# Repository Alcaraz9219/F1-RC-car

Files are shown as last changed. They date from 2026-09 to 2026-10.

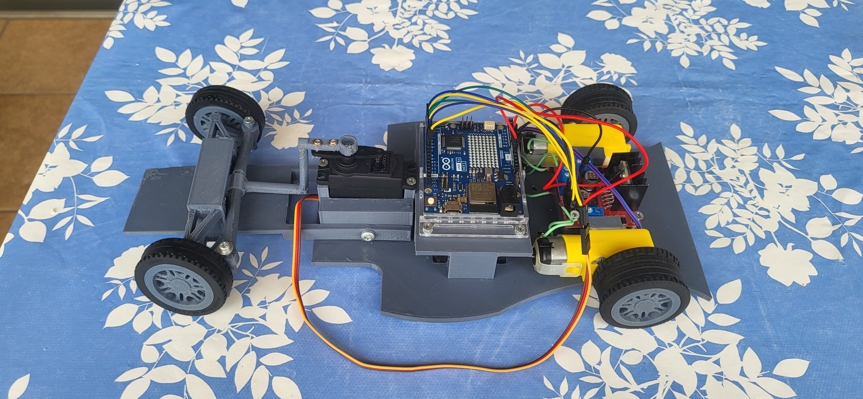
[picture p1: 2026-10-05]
Photos of the process/20260817_131121.jpg

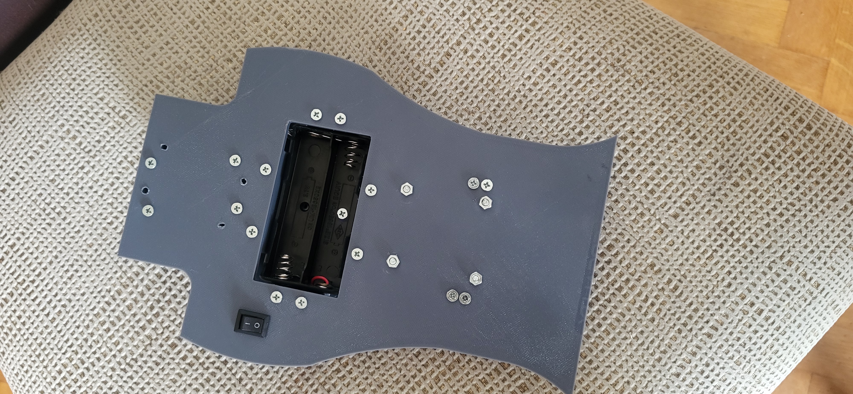
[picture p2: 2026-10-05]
Photos of the process/20260703_114534 (1).jpg

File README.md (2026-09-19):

🏎️ F1 RC Car

A custom-built, 3D-printed remote-controlled racing car inspired by Formula 1.

This project was developed as a hands-on electronics, CAD, 3D printing and programming project. The goal was to design and build the car from scratch, including the chassis, wheels, steering system and aerodynamic parts, while learning how the different electronic and mechanical systems work together.

 Features:
Custom 3D-printed chassis
Formula 1-inspired body and aerodynamic design
Rear-wheel drive
Two DC geared motors
Servo-controlled front steering
Wireless remote control
Custom-designed wheels
Custom front wing and nose
Arduino-based electronics
LCD display on the controller
Accelerator and brake controls
Joystick-based steering
NRF24L01 wireless communication
Designed and modified using CAD software

 Electronics:
Car
Arduino UNO R4 WiFi
L298N motor driver
2× geared DC motors
20 kg metal gear steering servo
2× 18650 batteries
NRF24L01 PA+LNA wireless module
LM2596 buck converter
Controller
Arduino UNO R3
NRF24L01 PA+LNA wireless module
Joystick
16×2 I2C LCD
Accelerator button
Brake button

Wireless Control:

The car and controller communicate using NRF24L01 PA+LNA modules.

The controller sends the steering and driving commands wirelessly to the Arduino on the car. The NRF24L01 modules replaced the original 433 MHz RF system to provide a more reliable and capable communication system.

The communication uses the Arduino's hardware SPI interface.

 Software:

The project is programmed using Arduino/C++.

The software is divided into two main parts:

Controller:

The controller reads:

Joystick position
Accelerator button
Brake button

It then sends these values wirelessly to the car.

Car

The car receives the controller data and converts it into:

Motor direction and speed
Steering servo position

The L298N controls the two drive motors, while a servo controls the front steering.

 CAD & 3D Printing:

A large part of the project was designing the mechanical components myself.

The project includes CAD and 3D-printable files for components such as:

Chassis
Motor supports
Arduino supports
L298N support
Battery holder
Steering components
Steering linkage
Wheels
Front wing
Front nose
Other mounting components

Different versions of several parts were designed, printed and tested before reaching the final versions.

Design Process:

The car was developed iteratively rather than designing everything perfectly on the first attempt.

The general process was:

Initial F1-inspired concept
Chassis design
Design of electronic and motor mounts
3D printing and physical testing
Modification of parts that did not fit correctly
Steering mechanism development
Wheel and aerodynamic component design
Electronics assembly
Motor testing
Steering servo testing
Wireless communication development
Integration of the different systems

Testing and redesigning parts was an important part of the project.

 What I Learned

Through this project I learned about:

Arduino programming
Wireless communication
SPI communication
Motor drivers
DC motors
Servo motors
Voltage regulation
Battery-powered electronics
CAD design
3D printing
Mechanical prototyping
Iterative design
Troubleshooting electronics
Integrating hardware and software

One of the main lessons from the project was that designing a system is only part of the work. A large part of the process is testing, finding problems and redesigning the components until everything works together.

 Future Improvements

Possible future improvements include:

DRS system using an SG90 servo
Lights
Additional controller buttons
Improved bodywork
More aerodynamic components
Improved wireless communication
Additional telemetry
More advanced driving controls
 Project Status

The main car structure, steering, motors, controller and wireless communication systems have been developed and tested.

The project is currently considered a functional prototype, with additional features planned for future development.

Made as a learning project combining CAD, 3D printing, electronics and programming.

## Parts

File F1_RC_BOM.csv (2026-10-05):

Item | Quantity | Unit | Description | Estimated Price (€)
Arduino UNO R4 WiFi | 1 | unit | Main car microcontroller | 30.0
Arduino UNO R3 | 1 | unit | Remote controller microcontroller | 29.0
ESP32 Plus STEAMakers | 1 | unit | Controller prototype; ultimately not used | 30.0
20KG metal gear steering servo | 1 | unit | Front steering servo | 15.0
L298N motor driver | 1 | unit | Dual DC motor driver | 4.0
Geared DC motors | 2 | unit | Rear-wheel drive motors | 15.0
433 MHz RF transmitter/receiver set | 1 | set | Initial wireless communication system | 5.0
NRF24L01 PA+LNA modules | 2 | unit | Long-range wireless transceivers | 10.0
SG90 servo | 1 | unit | DRS actuator | 3.0
2x18650 battery holder | 1 | unit | Battery holder | 2.0
3.7 V lithium batteries | 2 | unit | 18650 cells | 10.0
LM2596 buck converter | 1 | unit | Adjustable DC-DC voltage regulator | 2.0
Terminal blocks | 6 | unit | Electrical connections | 3.0
Jumper wires | 42 | unit | Approximate quantity used | 3.0
Power switch | 1 | unit | Main power switch | 2.0
16x2 I2C LCD | 1 | unit | Remote controller display | 5.0
Joystick module | 1 | unit | Remote steering input | 2.0
Push buttons | 2 | unit | Accelerator and brake controls | 1.0
9 V battery | 1 | unit | Prototype/testing power source | 2.0
Machine screws | 56 | unit | Fasteners | 5.0
Wood screws | 4 | unit | Fasteners | 1.0
Washers | 4 | unit | Fasteners | 1.0
Nuts | 10 | unit | Fasteners | 1.0
Threaded inserts | 12 | unit | Threaded inserts for printed parts | 5.0
Tires | 4 | unit | Four wheels | 8.0
Gray PETG filament | 1 | kg roll | 3D printing material | 20.0

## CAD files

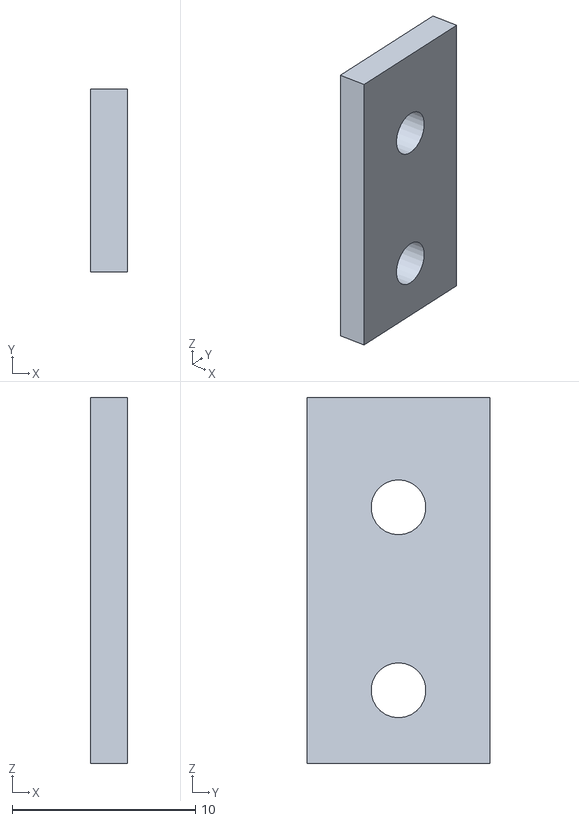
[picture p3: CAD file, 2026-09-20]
Cad/Bumper and front wing/Front bumper assembly.stl
2.00 x 10.0 x 20.0

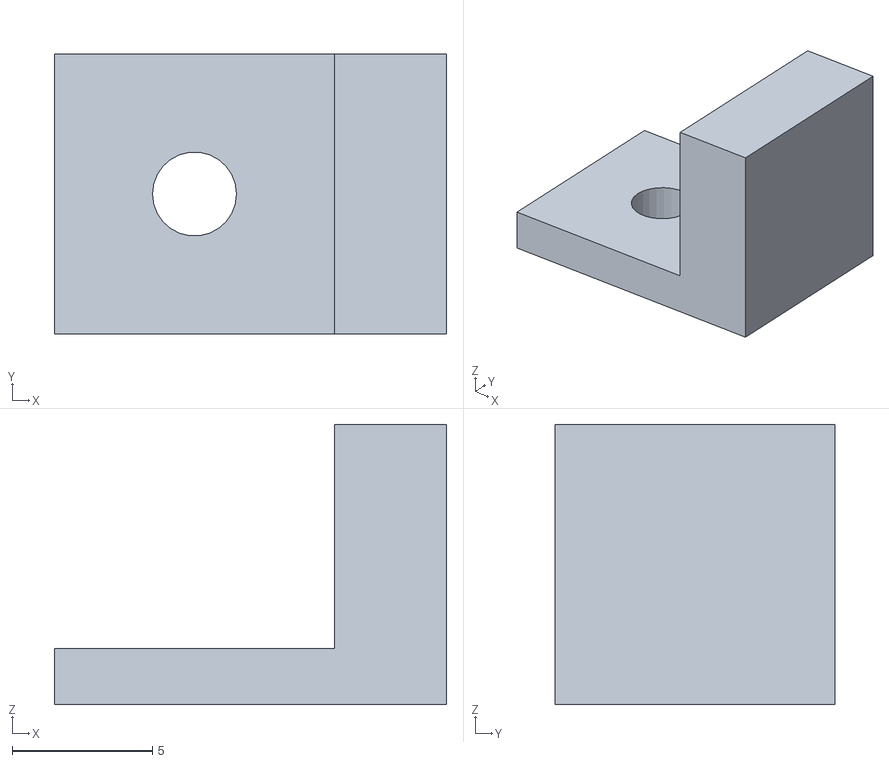
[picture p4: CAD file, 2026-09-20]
Cad/Bumper and front wing/Front bumper assembly for the above part.stl
14.0 x 10.0 x 10.0

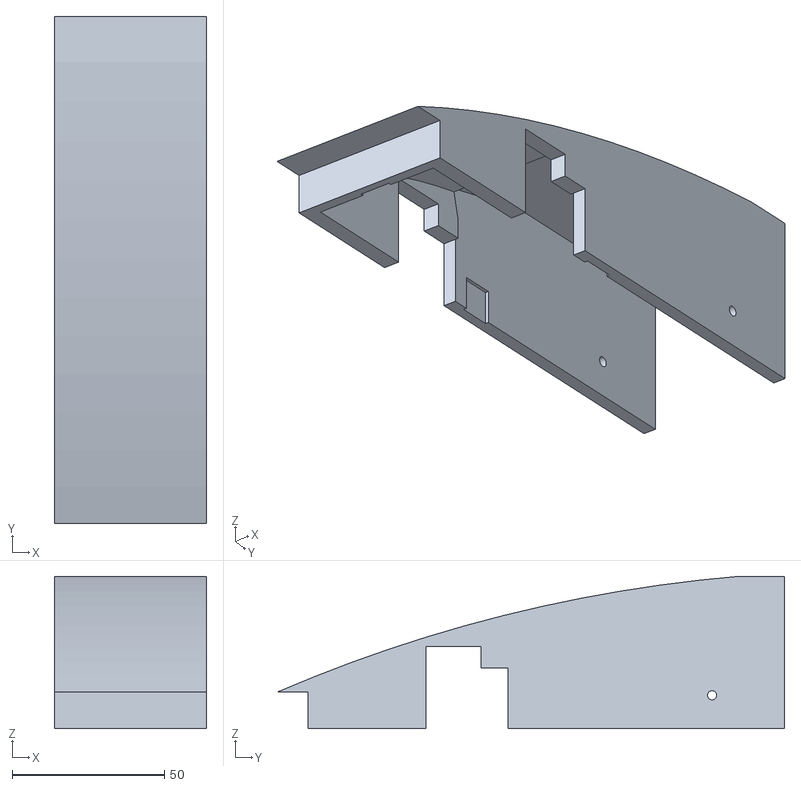
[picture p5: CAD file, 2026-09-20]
Cad/Bumper and front wing/Front bumper above part.stl
50.0 x 166.6 x 50.1

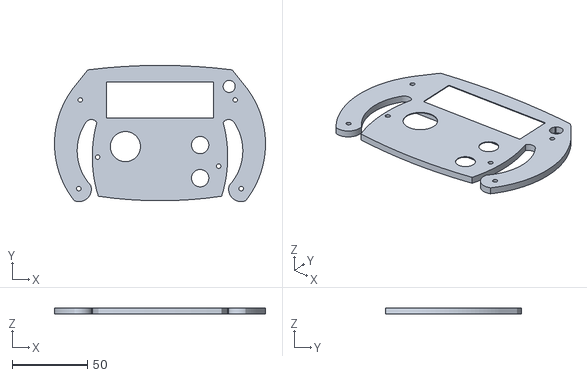
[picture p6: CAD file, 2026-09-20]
Cad/Remote control/Remote control above part.stl
140.3 x 90.6 x 4.00

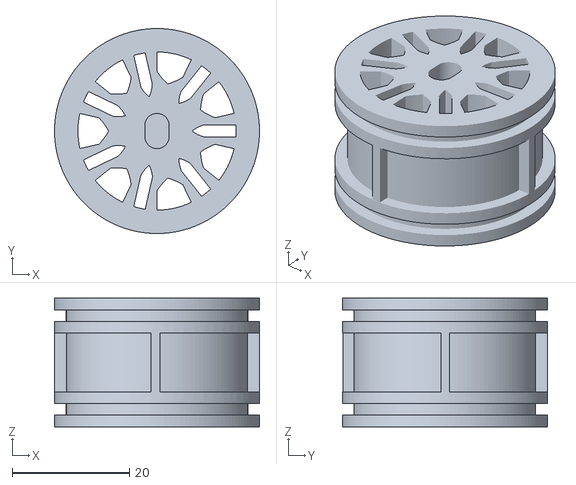
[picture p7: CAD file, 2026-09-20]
Cad/Wheels/Behind wheel.stl
35.0 x 35.0 x 22.0

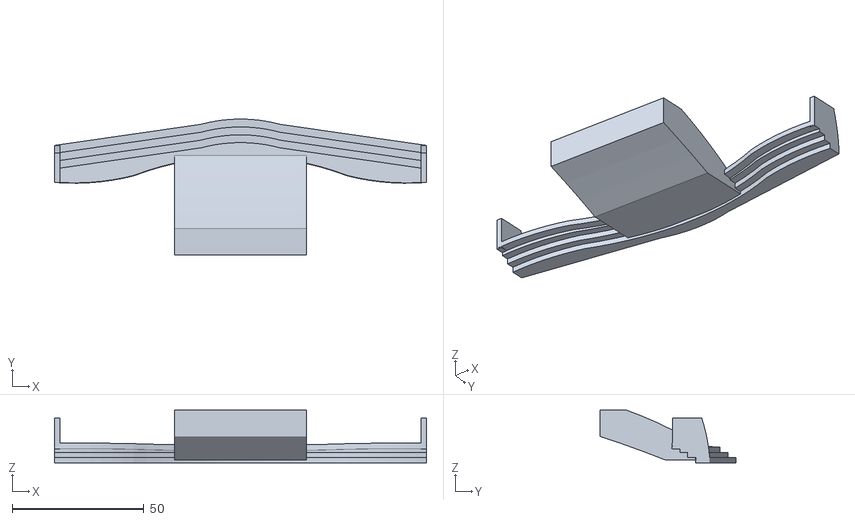
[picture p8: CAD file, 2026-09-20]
Cad/Bumper and front wing/Front wing.stl
141.0 x 51.5 x 20.0

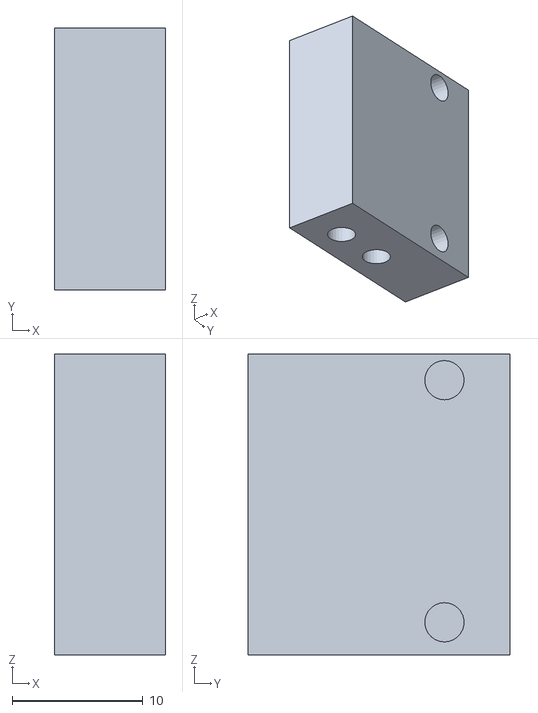
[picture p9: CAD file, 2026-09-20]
Cad/Chassis and electronic mounts/Right motor support.stl
8.50 x 20.0 x 23.0

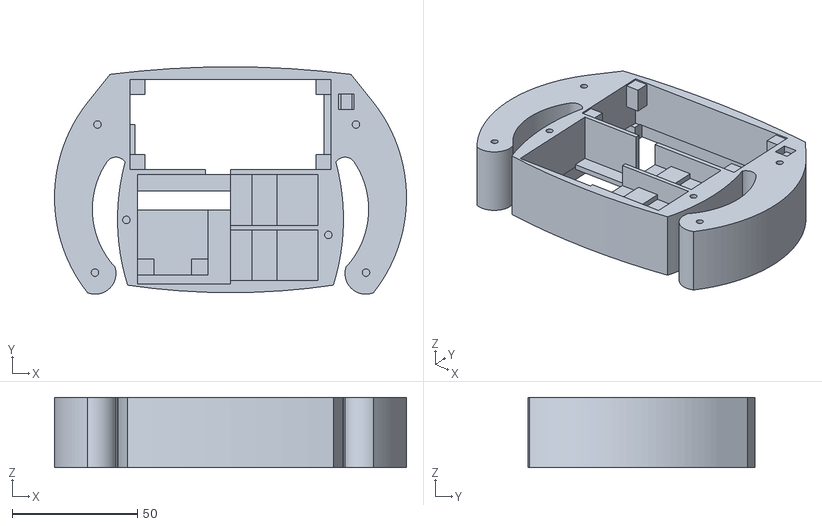
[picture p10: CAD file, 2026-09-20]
Cad/Remote control/Remote control middle part.stl
140.3 x 90.6 x 28.0

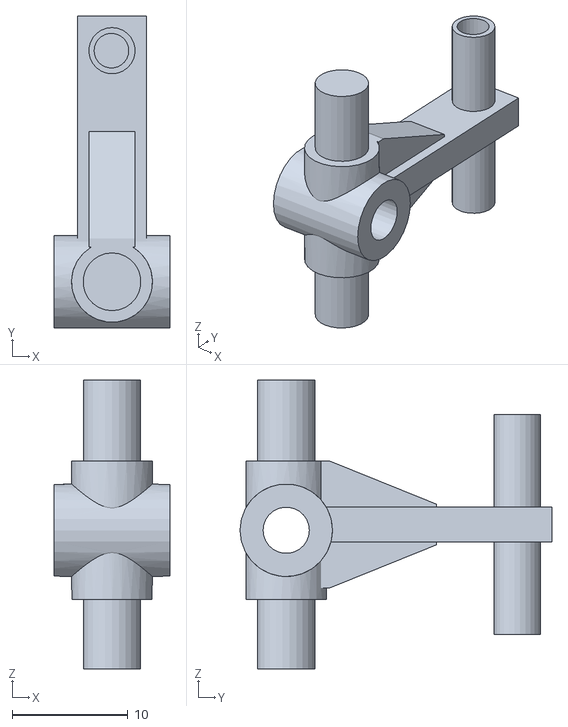
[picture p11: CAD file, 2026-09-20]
Cad/Steering/car hub.stl
10.0 x 27.0 x 25.0

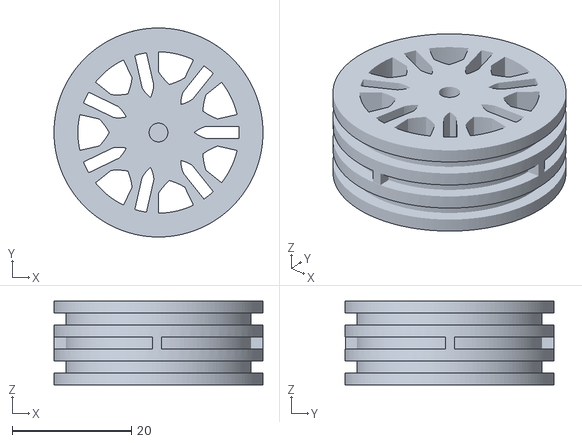
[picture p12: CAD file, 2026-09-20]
Cad/Wheels/Front wheel.stl
35.0 x 35.0 x 14.0

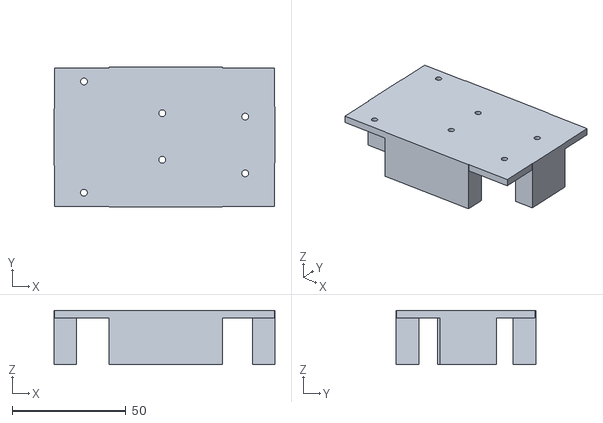
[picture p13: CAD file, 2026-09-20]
Cad/Chassis and electronic mounts/Arduino support.stl
97.4 x 61.5 x 24.0

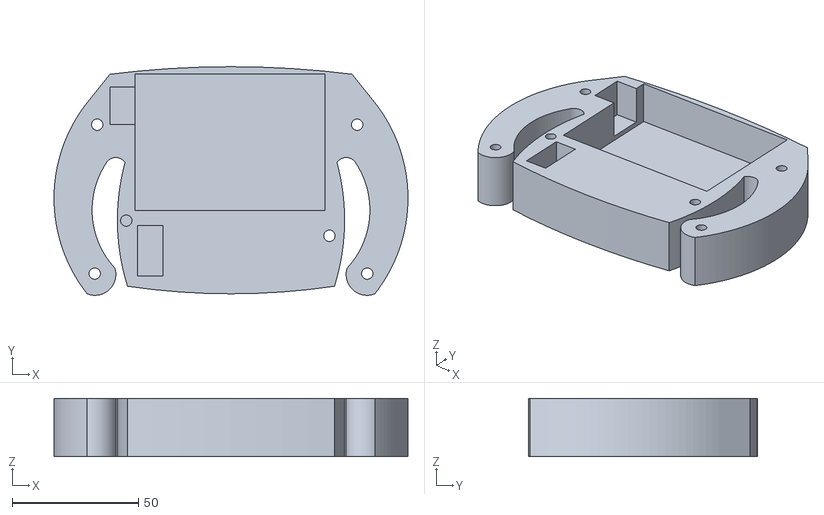
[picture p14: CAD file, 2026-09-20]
Cad/Remote control/Remote control under part.stl
140.3 x 90.6 x 23.0

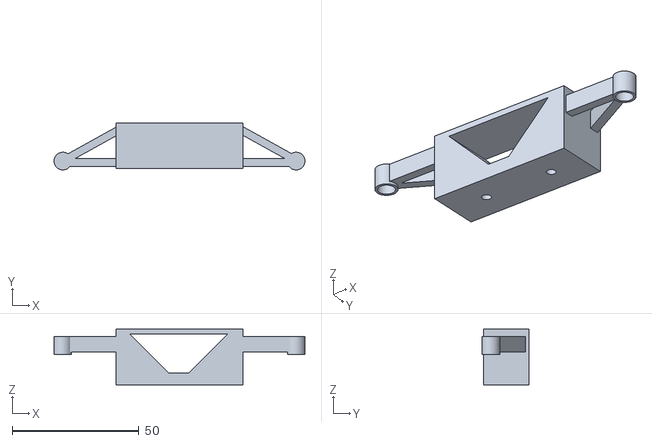
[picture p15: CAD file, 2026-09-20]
Cad/Steering/car hub above support.stl
99.0 x 18.5 x 22.0

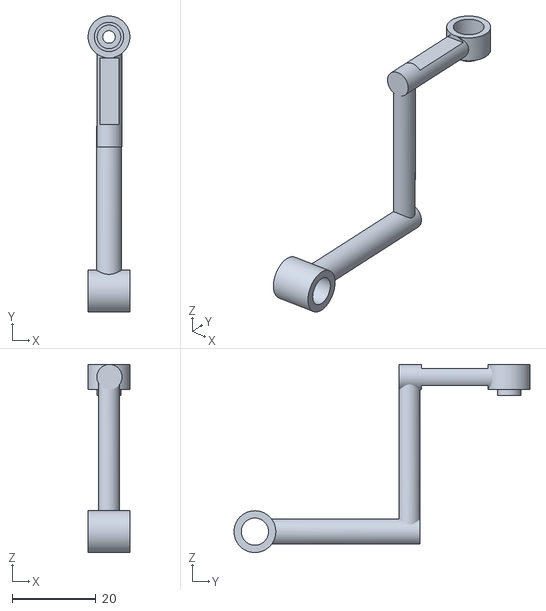
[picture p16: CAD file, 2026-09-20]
Cad/Steering/Servo motor bar.stl
10.0 x 70.8 x 45.0

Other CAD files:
Cad/Step/F1-RC-Car.step
Cad/Step/F1-RC-Remote control.step
Cad/Chassis and electronic mounts/Left motor support.stl
Cad/Bumper and front wing/Front bumper under part.stl
Cad/Chassis and electronic mounts/Chassis.stl
Cad/Chassis and electronic mounts/L298N screws support.stl
Cad/Chassis and electronic mounts/L298N support.stl
Cad/Chassis and electronic mounts/Servo motor support.stl
Cad/Steering/Car hub mushroom.stl
Cad/Steering/Steering bar.stl
Cad/Steering/Steering column washer.stl
Cad/Steering/car hub under support.stl

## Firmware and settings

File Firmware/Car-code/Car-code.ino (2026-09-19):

#include <SPI.h>
#include <RF24.h>
#include <Servo.h>
#include <stdint.h>

// ==================================================
// NRF24L01
// CE = D9
// CSN = D10
// ==================================================

RF24 radio(9, 10);

const byte direccionRadio[6] = "F1CAR";

// ==================================================
// SERVO
// ==================================================

Servo servoDireccion;

const int SERVO_PIN = 8;

const int SERVO_CENTRO = 80;
const int SERVO_IZQUIERDA = 65;
const int SERVO_DERECHA = 95;

// ==================================================
// L298N
// ==================================================

const int ENA = 5;
const int IN1 = 2;
const int IN2 = 3;

const int ENB = 6;
const int IN3 = 4;
const int IN4 = 7;

// ==================================================
// DATOS
// ==================================================

struct DatosMando {
  int16_t acelerador;
  int16_t direccion;
};

DatosMando datos;

// ==================================================
// SEGURIDAD
// ==================================================

unsigned long ultimaRecepcion = 0;

const unsigned long TIMEOUT_RF = 500;

// ==================================================
// SETUP
// ==================================================

void setup() {

  Serial.begin(115200);

  // Motores
  pinMode(ENA, OUTPUT);
  pinMode(IN1, OUTPUT);
  pinMode(IN2, OUTPUT);

  pinMode(ENB, OUTPUT);
  pinMode(IN3, OUTPUT);
  pinMode(IN4, OUTPUT);

  // Servo
  servoDireccion.attach(SERVO_PIN);
  servoDireccion.write(SERVO_CENTRO);

  pararMotores();

  // NRF24
  if (!radio.begin()) {

    Serial.println("ERROR NRF24");

    while (1) {
      pararMotores();
    }
  }

  radio.setPALevel(RF24_PA_MAX);
  radio.setDataRate(RF24_250KBPS);
  radio.setChannel(108);

  radio.openReadingPipe(1, direccionRadio);

  radio.startListening();

  datos.acelerador = 0;
  datos.direccion = 0;

  ultimaRecepcion = millis();

  Serial.println("COCHE NRF24 OK");
}

// ==================================================
// LOOP
// ==================================================

void loop() {

  // ==================================================
  // RECIBIR
  // ==================================================

  if (radio.available()) {

    radio.read(
      &datos,
      sizeof(datos)
    );

    ultimaRecepcion = millis();

    // Limitar valores
    datos.acelerador =
      constrain(datos.acelerador, -100, 100);

    datos.direccion =
      constrain(datos.direccion, -100, 100);

    // ==================================================
    // DIRECCION
    // ==================================================

    int angulo = map(
      datos.direccion,
      -100,
      100,
      SERVO_IZQUIERDA,
      SERVO_DERECHA
    );

    angulo = constrain(
      angulo,
      SERVO_IZQUIERDA,
      SERVO_DERECHA
    );

    servoDireccion.write(angulo);

    // ==================================================
    // MOTORES
    // ==================================================

    if (datos.acelerador > 50) {

      adelante();

    } else if (datos.acelerador < -50) {

      atras();

    } else {

      pararMotores();
    }

    // ==================================================
    // SERIAL
    // ==================================================

    Serial.print("Acelerador: ");
    Serial.print(datos.acelerador);

    Serial.print(" | Direccion: ");
    Serial.print(datos.direccion);

    Serial.print(" | Servo: ");
    Serial.println(angulo);
  }

  // ==================================================
  // SEGURIDAD
  // ==================================================

  if (millis() - ultimaRecepcion > TIMEOUT_RF) {

    pararMotores();

    servoDireccion.write(SERVO_CENTRO);
  }
}

// ==================================================
// ADELANTE
// ==================================================

void adelante() {

  digitalWrite(IN1, HIGH);
  digitalWrite(IN2, LOW);

  digitalWrite(IN3, HIGH);
  digitalWrite(IN4, LOW);

  analogWrite(ENA, 255);
  analogWrite(ENB, 255);
}

// ==================================================
// ATRAS
// ==================================================

void atras() {

  digitalWrite(IN1, LOW);
  digitalWrite(IN2, HIGH);

  digitalWrite(IN3, LOW);
  digitalWrite(IN4, HIGH);

  analogWrite(ENA, 255);
  analogWrite(ENB, 255);
}

// ==================================================
// PARAR
// ==================================================

void pararMotores() {

  analogWrite(ENA, 0);
  analogWrite(ENB, 0);

  digitalWrite(IN1, LOW);
  digitalWrite(IN2, LOW);

  digitalWrite(IN3, LOW);
  digitalWrite(IN4, LOW);
}

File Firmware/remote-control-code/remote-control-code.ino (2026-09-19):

#include <SPI.h>
#include <RF24.h>
#include <Wire.h>
#include <LiquidCrystal_I2C.h>
#include <stdint.h>

// ==================================================
// NRF24L01
// CE = D9
// CSN = D10
// ==================================================

RF24 radio(9, 10);

const byte direccionRadio[6] = "F1CAR";

// ==================================================
// LCD
// ==================================================

LiquidCrystal_I2C lcd(0x27, 16, 2);

// ==================================================
// CONTROLES
// ==================================================

const int JOYSTICK_X = A0;

const int BOTON_ACELERADOR = 2;
const int BOTON_FRENO = 3;

// ==================================================
// DATOS
// ==================================================

struct DatosMando {
  int16_t acelerador;
  int16_t direccion;
};

DatosMando datos;

// ==================================================
// JOYSTICK
// ==================================================

const int CENTRO_X = 512;
const int ZONA_MUERTA = 80;

// ==================================================
// SETUP
// ==================================================

void setup() {

  Serial.begin(115200);

  pinMode(JOYSTICK_X, INPUT);

  pinMode(BOTON_ACELERADOR, INPUT_PULLUP);
  pinMode(BOTON_FRENO, INPUT_PULLUP);

  // LCD
  lcd.init();
  lcd.backlight();
  lcd.clear();

  lcd.setCursor(0, 0);
  lcd.print("F1 RC CAR");

  lcd.setCursor(0, 1);
  lcd.print("INICIANDO...");

  delay(1000);

  // NRF24
  if (!radio.begin()) {

    lcd.clear();
    lcd.setCursor(0, 0);
    lcd.print("ERROR NRF24");

    Serial.println("ERROR NRF24");

    while (1);
  }

  radio.setPALevel(RF24_PA_MAX);
  radio.setDataRate(RF24_250KBPS);
  radio.setChannel(108);

  radio.openWritingPipe(direccionRadio);

  radio.stopListening();

  lcd.clear();

  lcd.setCursor(0, 0);
  lcd.print("NRF24 OK");

  lcd.setCursor(0, 1);
  lcd.print("MANDO LISTO");

  delay(1500);
}

// ==================================================
// LOOP
// ==================================================

void loop() {

  // ==================================================
  // DIRECCION
  // ==================================================

  int x = analogRead(JOYSTICK_X);

  int diferenciaX = x - CENTRO_X;

  if (abs(diferenciaX) < ZONA_MUERTA) {

    datos.direccion = 0;

  } else {

    datos.direccion = map(
      diferenciaX,
      -512,
      511,
      -100,
      100
    );

    datos.direccion = constrain(
      datos.direccion,
      -100,
      100
    );
  }

  // ==================================================
  // ACELERADOR / FRENO
  // ==================================================

  bool aceleradorPulsado =
    digitalRead(BOTON_ACELERADOR) == LOW;

  bool frenoPulsado =
    digitalRead(BOTON_FRENO) == LOW;

  if (aceleradorPulsado && !frenoPulsado) {

    datos.acelerador = 100;

  } else if (frenoPulsado && !aceleradorPulsado) {

    datos.acelerador = -100;

  } else {

    datos.acelerador = 0;
  }

  // ==================================================
  // TRANSMITIR
  // ==================================================

  radio.write(
    &datos,
    sizeof(datos)
  );

  // ==================================================
  // LCD
  // ==================================================

  lcd.clear();

  lcd.setCursor(0, 0);
  lcd.print("DIR:");

  if (datos.direccion < -10) {

    lcd.print("IZQ");

  } else if (datos.direccion > 10) {

    lcd.print("DER");

  } else {

    lcd.print("RECT");
  }

  lcd.setCursor(0, 1);

  if (datos.acelerador == 100) {

    lcd.print("ADELANTE");

  } else if (datos.acelerador == -100) {

    lcd.print("ATRAS");

  } else {

    lcd.print("PARADO");
  }

  // ==================================================
  // SERIAL
  // ==================================================

  Serial.print("Direccion: ");
  Serial.print(datos.direccion);

  Serial.print(" | Acelerador: ");
  Serial.println(datos.acelerador);

  delay(50);
}

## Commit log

2026-09-19 README for F1 RC Car project
    Added detailed project description, features, electronics, software, CAD & 3D printing information, design process, lessons learned, future improvements, and project status.
2026-09-20 Create Cad
